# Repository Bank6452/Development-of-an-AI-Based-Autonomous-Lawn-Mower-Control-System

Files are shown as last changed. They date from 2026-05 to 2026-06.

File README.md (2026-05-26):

# 🚜 Autonomous Lawn Mower Robot — ROS2 & STM32

<div align="center">







**โปรเจคจบการศึกษา (Senior Project) ปีการศึกษา 2567**<br>
ระบบรถตัดหญ้าอัตโนมัติควบคุมด้วย ROS 2 — แม่นยำระดับเซนติเมตร ปลอดภัยด้วย AI

<br>

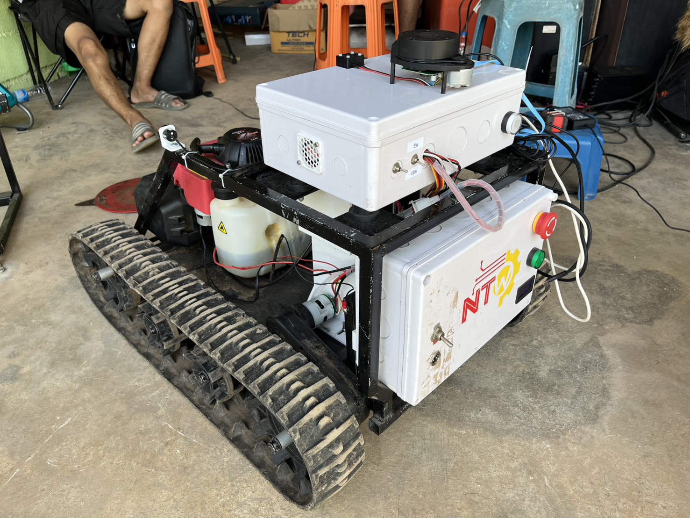
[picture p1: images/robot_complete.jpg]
Robot Complete


</div>

---

## 📖 ภาพรวมโปรเจค

ระบบรถตัดหญ้าอัตโนมัติ (Autonomous Lawn Mower) แบบ **Differential Drive** พัฒนาด้วย **ROS 2 Humble** บน **Raspberry Pi 5** ควบคุมฮาร์ดแวร์ผ่าน **STM32F103C8T6** โดยผสาน Sensor หลายตัว (RTK GPS, LiDAR, IMU, Encoder) ด้วยเทคนิค **Extended Kalman Filter (EKF)** เพื่อการ Localization ที่แม่นยำ พร้อมระบบ **Geofencing**, **YOLO Vision**, และ **Nav2 Navigation Stack**

---

## 🎬 Demo

### 🌿 ตัดหญ้าด้วยระบบอัตโนมัติ (Real Field Test)

<div align="center">

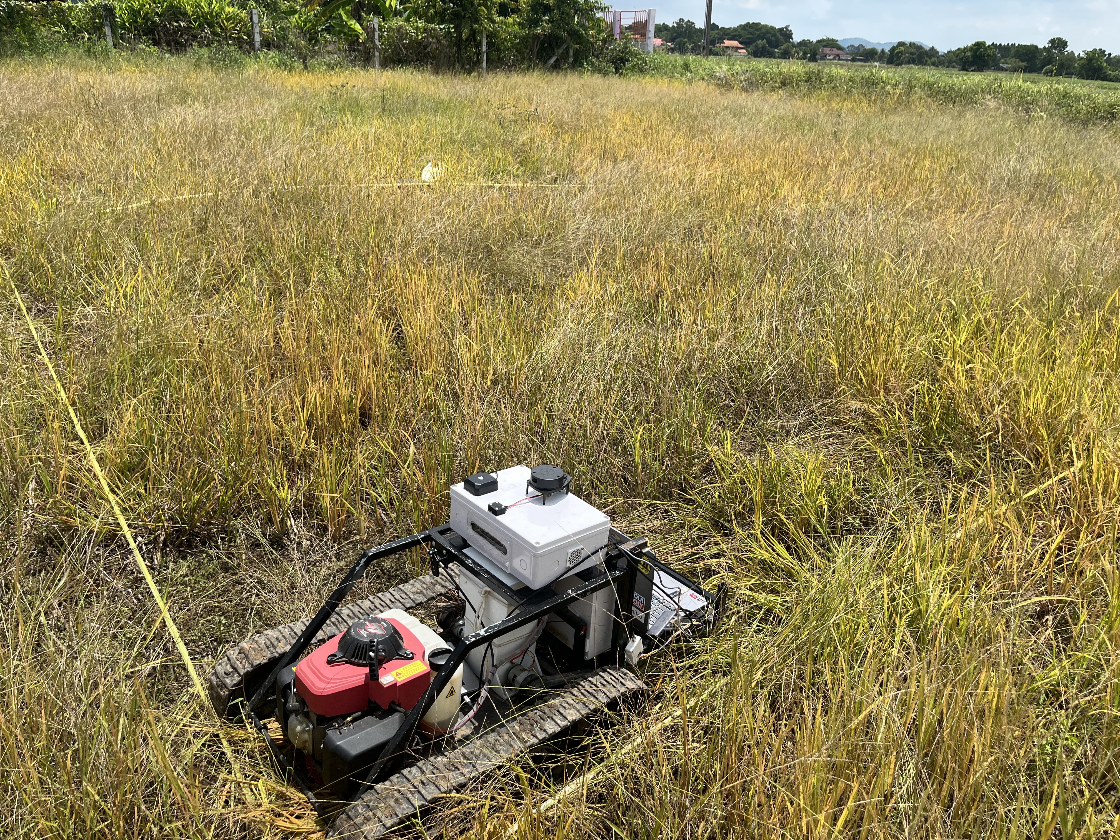
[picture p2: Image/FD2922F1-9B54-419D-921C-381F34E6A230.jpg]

*รถตัดหญ้าอัตโนมัติกำลังปฏิบัติงานในพื้นที่จริง — เห็นแนวการตัดแบบ Zigzag อย่างชัดเจน และเส้นเชือกกำหนดขอบเขต (Geofence) โดยรอบ*

<br>

| รถตัดหญ้าอัตโนมัติขณะทำงานในสนาม | ภาพรวมพื้นที่และแนวการตัด |
|:---:|:---:|
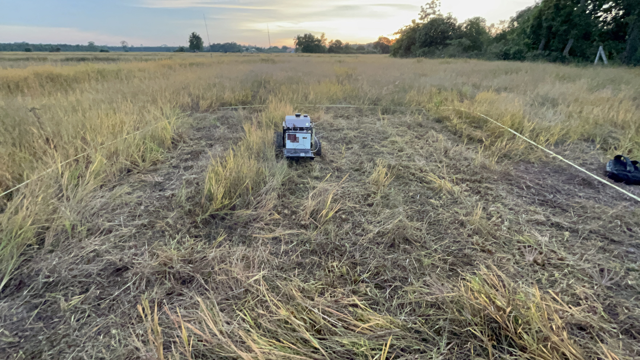
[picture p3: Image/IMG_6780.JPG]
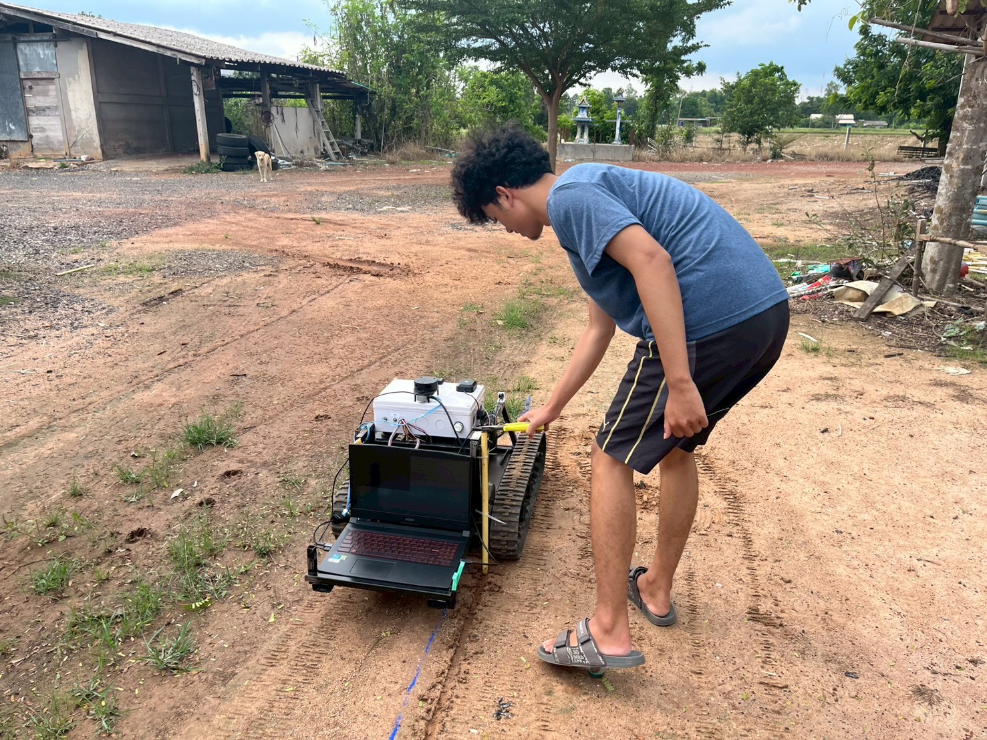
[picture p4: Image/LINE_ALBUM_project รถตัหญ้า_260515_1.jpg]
|  |  |

| | | |
|:---:|:---:|:---:|
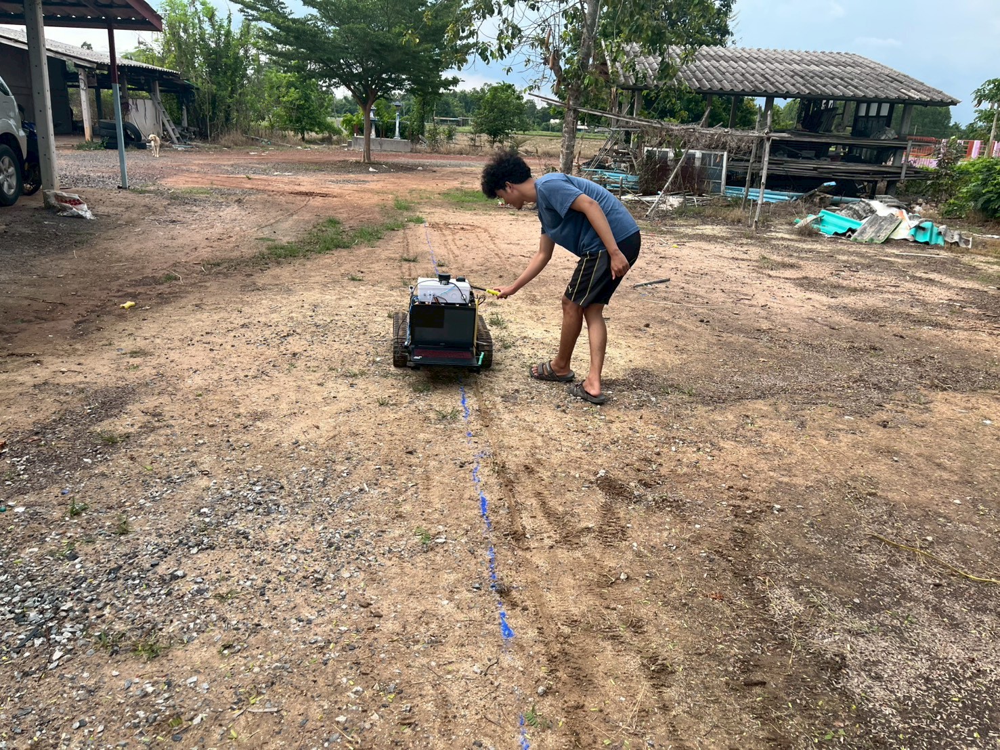
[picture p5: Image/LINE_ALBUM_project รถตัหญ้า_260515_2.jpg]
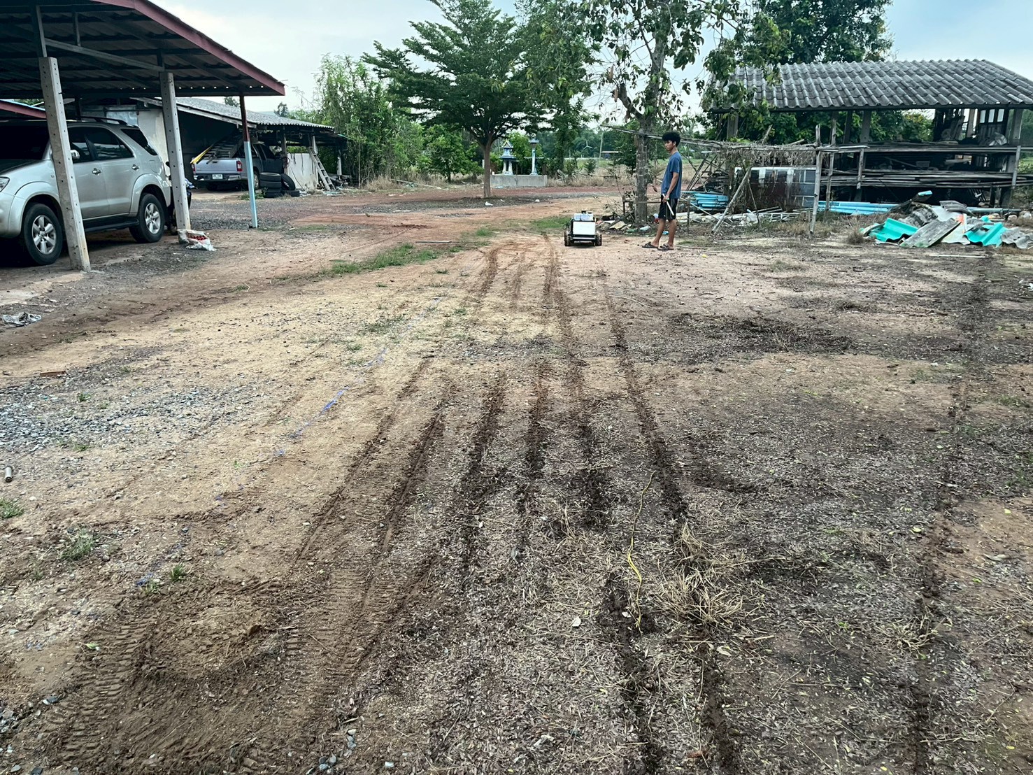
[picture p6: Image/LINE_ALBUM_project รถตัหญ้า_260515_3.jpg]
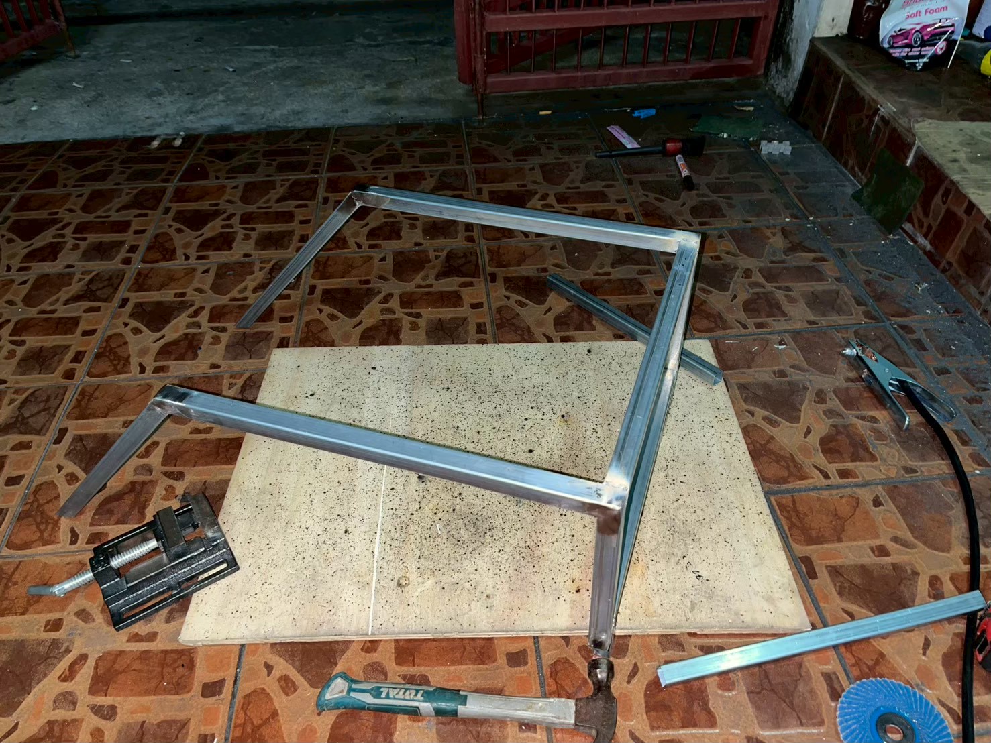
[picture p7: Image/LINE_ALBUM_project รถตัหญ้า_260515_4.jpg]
|  |  |  |
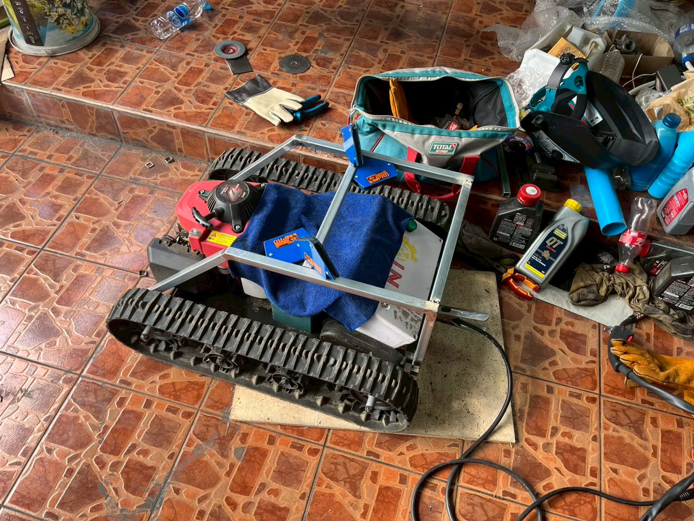
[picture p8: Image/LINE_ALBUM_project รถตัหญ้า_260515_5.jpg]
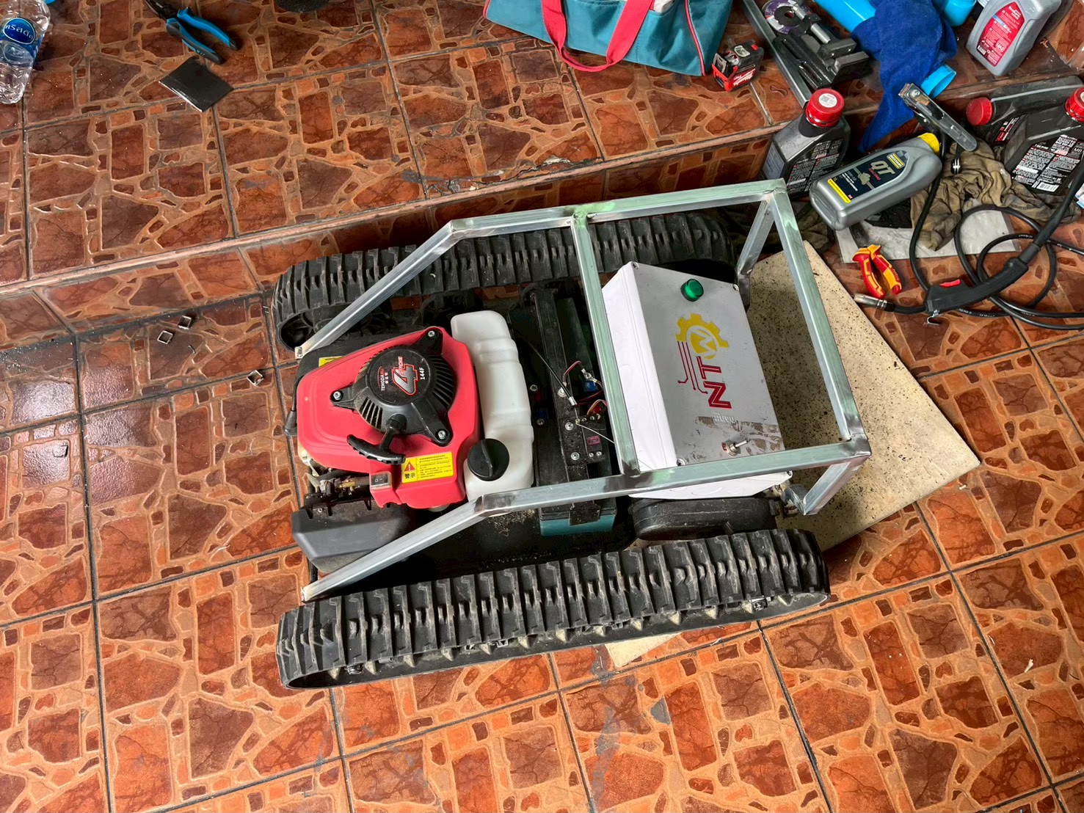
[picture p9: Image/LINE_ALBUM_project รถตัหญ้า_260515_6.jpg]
|  |  |  |

> 📹 **วิดีโอสาธิตการตัดหญ้าจริง:** [`Image/IMG_6782.MOV`](Image/IMG_6782.MOV)

</div>

### ทดสอบในสนามจริง (Setup & Navigation)

<div align="center">

| ตั้งค่าและเตรียมระบบ | วิ่งทดสอบอัตโนมัติ |
|:---:|:---:|
| Setup | Run |

Autonomous Field Test
*รถวิ่งอัตโนมัติครอบคลุมพื้นที่ด้วย Coverage Path Planning*

</div>

### ระบบ AI Vision + LiDAR Mapping (RViz2)

<div align="center">

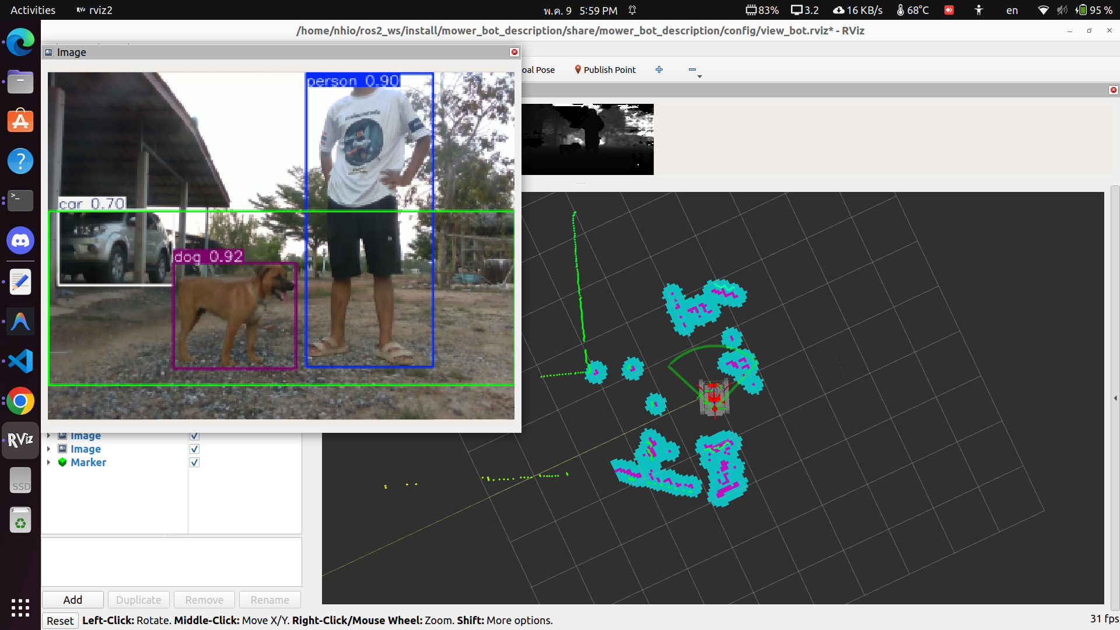
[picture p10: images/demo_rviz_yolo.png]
RViz YOLO Demo

*YOLO ตรวจจับคนและสัตว์ (ซ้าย) + LiDAR Point Cloud Map (ขวา) แบบ Real-time*

</div>

### วิดีโอสาธิต

> 📹 ดูวิดีโอทดสอบในสนามจริงได้ที่: [`Video/demo_field_test.mp4`](Video/demo_field_test.mp4)

---

## ✨ ฟีเจอร์หลัก

| ฟีเจอร์ | รายละเอียด |
|---|---|
| 📡 **RTK GPS + EKF Fusion** | Localization แม่นยำระดับเซนติเมตร โดยรวม GPS และ Wheel Odometry ด้วย Extended Kalman Filter |
| 🗺️ **SLAM & Nav2** | สร้างแผนที่อัตโนมัติ และวางแผนเส้นทางตัดหญ้าแบบ Zig-Zag Coverage Path |
| 🛡️ **Geofencing** | กำหนดขอบเขตการทำงานด้วย GPS Waypoints ป้องกันรถออกนอกพื้นที่ |
| 👁️ **YOLO Vision** | ตรวจจับสิ่งกีดขวางด้วย YOLOv11 + Intel RealSense Depth Camera |
| 💓 **Heartbeat Safety** | ระบบตรวจสอบการเชื่อมต่อ — หยุดรถทันทีเมื่อขาดการเชื่อมต่อ |
| 🔧 **Engine Control** | สตาร์ท/ดับเครื่องยนต์และควบคุม Throttle ผ่าน Software |
| 🎮 **Gazebo Simulation** | จำลองระบบก่อน Deploy จริง รองรับ Nav2 + EKF ใน Simulation |
| 📊 **Real-time Dashboard** | แสดงสถานะระบบแบบ Real-time ผ่าน Terminal |

---

## 🔩 ฮาร์ดแวร์ (Hardware)

<div align="center">

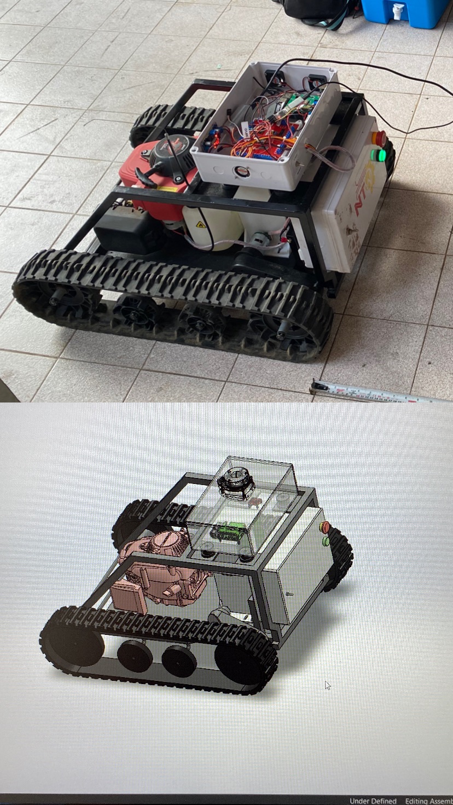
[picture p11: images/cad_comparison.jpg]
CAD vs Real

*CAD Design (ล่าง) เปรียบเทียบกับหุ่นยนต์ที่สร้างจริง (บน)*

</div>

| ชิ้นส่วน | รุ่น/ประเภท | หน้าที่ |
|---|---|---|
| Main Computer | **Raspberry Pi 5** | รัน ROS 2, Navigation, AI |
| Microcontroller | **STM32F103C8T6** (Bluepill) | ควบคุมมอเตอร์, อ่าน Encoder/IMU |
| GPS | **RTK GPS** (NTRIP via KMUTNB65) | Localization แม่นยำ |
| LiDAR | **RPLiDAR** | SLAM และตรวจจับสิ่งกีดขวาง |
| Camera | **Intel RealSense D4xx** | YOLO Object Detection + Depth |
| IMU | **MPU6050 / BNO055** | วัดมุมเอียงและ Angular Velocity |
| Encoder | **Hall Effect Encoder** | วัด Wheel Odometry |
| Drive System | **Rubber Track (สายพาน)** | เคลื่อนที่บนพื้นที่ขรุขระ |
| Engine | **Honda GX Series** | ใบมีดตัดหญ้า |

---

## 🏗️ สถาปัตยกรรมระบบ

```
┌─────────────────────────────────────────────────────────┐
│             Raspberry Pi / Computer 5 (ROS 2)           │
│                                                         │
│  ┌──────────┐  ┌────────────┐  ┌──────────────────────┐ │
│  │  Nav2    │  │   EKF      │  │   Geofence & Planner │ │
│  │ Stack    │──│Localization│  │   (Safety Layer)     │ │
│  └──────────┘  └─────┬──────┘  └──────────────────────┘ │
│       │              │                                  │
│  ┌────▼─────────────▼─────────────────────────────┐     │
│  │              ROS 2 Topic Bus                   │     │
│  └────┬──────────┬─────────┬──────────────────────┘     │
│       │          │         │                            │
│  ┌────▼───┐ ┌────▼───┐ ┌───▼────┐                       │
│  │RPLiDAR │ │RTK GPS │ │ Camera │                       │
│  │ Node   │ │(NTRIP) │ │(YOLO)  │                       │
│  └────────┘ └────────┘ └────────┘                       │
└──────────────────────────┬──────────────────────────────┘
                           │ Serial (UART)
┌──────────────────────────▼──────────────────────────────┐
│                  STM32F103C8T6                          │
│   Motor Driver │ Encoder Reading │ IMU │ Engine Control │
└─────────────────────────────────────────────────────────┘
```

---

## 📂 โครงสร้างโปรเจค

```
ros2_final_project_ws/
├── src/
│   ├── robot_bridge/            # 🧠 ROS2 Package หลัก
│   │   ├── robot_bridge/        # Python nodes
│   │   │   ├── auto_datum_node.py       # ตั้งจุด Datum GPS อัตโนมัติ
│   │   │   ├── geofence_and_planner.py  # Geofence + Coverage Path Planning
│   │   │   ├── geofence_enforcer.py     # Safety: บังคับขอบเขต GPS
│   │   │   ├── lawn_planner.py          # สร้างเส้นทาง Zig-Zag
│   │   │   ├── mow_zigzag.py            # Executor: สั่งวิ่งตามเส้นทาง
│   │   │   ├── ntrip_client.py          # RTK GPS via NTRIP
│   │   │   ├── robot_dashboard.py       # Real-time Status Dashboard
│   │   │   ├── teleop_stm.py            # Teleop → STM32 bridge
│   │   │   └── vision_node.py           # YOLOv11 + RealSense
│   │   ├── launch/
│   │   │   ├── hardware_bringup.launch.py   # เปิดระบบฮาร์ดแวร์ทั้งหมด
│   │   │   ├── localization.launch.py       # EKF Fusion
│   │   │   ├── navigation.launch.py         # Nav2 Stack
│   │   │   └── simulation.launch.py         # Gazebo Simulation
│   │   └── config/
│   │       ├── ekf.yaml             # EKF parameters
│   │       ├── nav2_params.yaml     # Nav2 configuration
│   │       └── twist_mux.yaml       # Velocity command priority
│   │
│   ├── mower_bot_description/   # 🤖 Robot URDF & Simulation
│   └── rplidar_ros/             # 📡 RPLiDAR Driver
│
├── config/                      # ⚙️ Runtime configs
│   ├── lawn_geofence.yaml       # Geofence waypoints (real)
│   ├── lawn_geofence_sim.yaml   # Geofence waypoints (sim)
│   └── udev/                    # USB device rules
│
├── images/                      # 🖼️ Project images (GitHub)
├── Video/                       # 🎬 Demo video
├── scripts/                     # 🔧 Utility & calibration scripts
├── extracted_project/           # 📦 STM32 PlatformIO firmware
├── docs/                        # 📚 Documentation
│
├── start_robot.sh               # 🚀 เปิดระบบหุ่นยนต์จริง (1 คำสั่ง)
├── start_sim.sh                 # 🎮 เปิด Simulation
├── setup_ws.sh                  # ⚡ Source workspace
└── COMMANDS.md                  # 📋 Command cheatsheet
```

---

## 🚀 วิธีติดตั้งและใช้งาน

### ความต้องการของระบบ (Prerequisites)

- **OS:** Ubuntu 22.04 (Jammy)
- **ROS 2:** Humble Hawksbill
- **Python:** 3.10+
- **Hardware:** Raspberry Pi 5 (แนะนำ RAM ≥ 8GB)

### 1. ติดตั้ง ROS 2 Humble

```bash
chmod +x install_ros2_humble.sh install_dependencies.sh
./install_ros2_humble.sh
./install_dependencies.sh
```

### 2. Clone และ Build

```bash
git clone https://github.com/<your-username>/ros2_final_project_ws.git
cd ros2_final_project_ws

pip3 install -r requirements.txt

source /opt/ros/humble/setup.bash
colcon build --symlink-install

source setup_ws.sh
```

### 3. ติดตั้ง udev rules (ทำครั้งเดียว)

```bash
sudo cp config/udev/98-gps.rules   /etc/udev/rules.d/
sudo cp config/udev/99-stm32.rules /etc/udev/rules.d/
sudo udevadm control --reload-rules && sudo udevadm trigger
```

---

## ▶️ การใช้งาน

### 🤖 เปิดระบบหุ่นยนต์จริง

```bash
cd ~/ros2_final_project_ws
./start_robot.sh
```

สคริปต์จะเปิด Terminal tabs อัตโนมัติ:

| แท็บ | ระบบ |
|-----|---|
| 1. HARDWARE | RPLiDAR, STM32, GPS, Camera |
| 2. LOCALIZATION | EKF Sensor Fusion |
| 3. NAVIGATION | Nav2 Path Planning |
| 4. SAFETY & PLANNER | Geofence + Coverage Path |
| 6. MOWING | Mow Executor (พิมพ์ `go` เพื่อเริ่ม) |
| 7. DASHBOARD | Real-time Status |

### 🎮 เปิด Simulation (Gazebo)

```bash
cd ~/ros2_final_project_ws
./start_sim.sh
```

### 🔧 Calibration

```bash
source setup_ws.sh
python3 scripts/calibrate_robot.py linear 1.0    # ระยะทาง
python3 scripts/calibrate_robot.py angular 90    # การหมุน
```

---

## 📡 ROS 2 Topics หลัก

| Topic | Type | รายละเอียด |
|---|---|---|
| `/cmd_vel` | `geometry_msgs/Twist` | คำสั่งความเร็ว (Nav2 → STM32) |
| `/odom_raw` | `nav_msgs/Odometry` | Wheel Odometry จาก STM32 |
| `/odometry/filtered` | `nav_msgs/Odometry` | EKF fused odometry |
| `/fix` | `sensor_msgs/NavSatFix` | RTK GPS position |
| `/scan` | `sensor_msgs/LaserScan` | RPLiDAR data |
| `/camera/yolo/debug_image` | `sensor_msgs/Image` | YOLO detection output |
| `/imu/data` | `sensor_msgs/Imu` | IMU data |

---

## 👥 ทีมผู้จัดทำ

| ชื่อ | รหัสนักศึกษา |
|-----|---|
| **นายพงศธร รอดพิพัฒน์** | 6703016410080 |
| **นายทินภัทร จิตต์บุญ** | 6703016410039 |
| **นายวัชรากร เพกรา** | 6703016410179 |

**อาจารย์ที่ปรึกษา:** ผศ.ดร.สุพจน์ แก้วกรณ์

**สังกัด:** ภาควิชาวิศวกรรมเมคคาทรอนิกส์ — มหาวิทยาลัยเทคโนโลยีพระจอมเกล้าพระนครเหนือ

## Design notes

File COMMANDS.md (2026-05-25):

# 📋 Command Cheatsheet — Mower Bot ROS2 Workspace

> ⚠️ **รันสคริปต์ทุกตัวจาก workspace root เสมอ**
> ```bash
> cd ~/ros2_final_project_ws   # หรือชื่อ folder จริงบนเครื่อง
> ```

---

## 🚀 เริ่มระบบหลัก

```bash
# [หุ่นยนต์จริง] — build + เปิดทุก tab อัตโนมัติ
cd ~/ros2_final_project_ws && colcon build --packages-select robot_bridge --symlink-install && source install/setup.bash
./start_robot.sh

# [Simulation] — build + เปิด Gazebo อัตโนมัติ
cd ~/ros2_final_project_ws
colcon build --packages-select robot_bridge --symlink-install
./start_sim.sh
```

---

## 🔨 Build & Source

```bash
cd ~/ros2_final_project_ws

# Build ทั้งหมด
colcon build --symlink-install

# Build เฉพาะ package
colcon build --packages-select robot_bridge --symlink-install
colcon build --packages-select mower_bot_description --symlink-install

# Source workspace (ทำทุกครั้งหลัง build)
source /opt/ros/humble/setup.bash
source install/setup.bash
```

---

## 🤖 Launch Files

```bash
cd ~/ros2_final_project_ws && source install/setup.bash

# Terminal 1 — Hardware
ros2 launch robot_bridge hardware_bringup.launch.py

# Terminal 2 — Localization (EKF)
ros2 launch robot_bridge localization.launch.py

# Terminal 3 — Navigation (Nav2)
ros2 launch robot_bridge navigation.launch.py

# Simulation (Gazebo)
ros2 launch robot_bridge simulation.launch.py
ros2 launch mower_bot_description launch_sim.launch.py

# Test IMU
ros2 launch robot_bridge imu_test.launch.py
```

---

## 🗺️ Nav2 + SLAM + Map

```bash
# SLAM
ros2 launch slam_toolbox online_async_launch.py use_sim_time:=True

# Nav2 bringup (Simulation)
ros2 launch nav2_bringup bringup_launch.py \
  use_sim_time:=True \
  map:=~/ros2_final_project_ws/src/mower_bot_description/maps/my_map.yaml \
  params_file:=~/ros2_final_project_ws/src/mower_bot_description/config/my_nav2_params.yaml

# RViz2
rviz2 -d ~/ros2_final_project_ws/src/mower_bot_description/config/view_bot.rviz
ros2 launch nav2_bringup bringup_launch.py use_sim_time:=True \
  map:=~/ros2_final_project_ws/src/mower_bot_description/maps/my_map.yaml

# ดู TF frames
ros2 run tf2_tools view_frames
```

---

## 🌿 Geofence & Planner

```bash
cd ~/ros2_final_project_ws && source install/setup.bash

# Geofence Enforcer (หุ่นยนต์จริง)
ros2 run robot_bridge geofence_enforcer \
  --ros-args -p geofence_file:=$(pwd)/config/lawn_geofence.yaml

# Geofence Enforcer (Simulation)
ros2 run robot_bridge geofence_enforcer \
  --ros-args -p geofence_file:=$(pwd)/config/lawn_geofence_sim.yaml

# Lawn Planner
ros2 run robot_bridge lawn_planner \
  --ros-args -p geofence_file:=$(pwd)/config/lawn_geofence.yaml

# Geofence + Planner รวม
ros2 run robot_bridge geofence_and_planner \
  --ros-args -p geofence_file:=$(pwd)/config/lawn_geofence.yaml

# Mowing Executor
ros2 run robot_bridge mow_zigzag
```

---

## 📡 GPS / NTRIP

```bash
./start_ntrip.sh

# หรือรันตรง
cd ~/ros2_final_project_ws && source install/setup.bash
ros2 run robot_bridge ntrip_client --ros-args \
  -p ip:="192.168.1.108" \
  -p port:=2116 \
  -p mountpoint:="KMUTNB65"
```

---

## 📷 Camera & Vision

```bash
cd ~/ros2_final_project_ws && source install/setup.bash

# เปิดกล้อง RealSense
ros2 launch realsense2_camera rs_launch.py \
  enable_color:=true enable_depth:=true \
  rgb_camera.color_profile:=640x480x15 \
  depth_module.profile:=640x480x15 \
  initial_reset:=true

# Vision Node (YOLO)
ros2 run robot_bridge vision_node

# ตรวจสอบ FPS กล้อง
ros2 topic hz /camera/yolo/debug_image
ros2 topic hz /camera/camera/color/image_raw

# GPU
nvidia-smi
```

---

## 🕹️ Teleop & Dashboard

```bash
cd ~/ros2_final_project_ws && source install/setup.bash

ros2 run teleop_twist_keyboard teleop_twist_keyboard
ros2 run robot_bridge robot_dashboard
ros2 run robot_bridge straight_line_test

# ส่ง cmd_vel โดยตรง
ros2 topic pub --once /cmd_vel_teleop geometry_msgs/msg/Twist \
  "{linear: {x: 0.2, y: 0.0, z: 0.0}, angular: {x: 0.0, y: 0.0, z: 0.0}}"
```

---

## 🧭 IMU / Compass

```bash
# Set zero compass (หันไปทางเหนือก่อน)
ros2 topic pub --once /imu/set_north std_msgs/msg/Empty {}

# Monitor IMU
ros2 topic echo /camera/camera/imu --field angular_velocity
ros2 topic echo /odometry/filtered --field pose.pose.orientation
```

---

## 🔧 Calibration

```bash
cd ~/ros2_final_project_ws && source install/setup.bash

# Calibrate (linear/angular) — ต้องรัน hardware_bringup ก่อน
python3 scripts/calibrate_robot.py linear 1.0
python3 scripts/calibrate_robot.py angular 90

python3 scripts/calibrate_linear.py

# Monitor topics
python3 scripts/topic_monitor.py
python3 scripts/monitor_imu_robot.py
```

---

## 🔌 USB / Serial Ports

```bash
ls /dev/tty{ACM,USB}*
ls /dev/serial/by-id/

# ติดตั้ง udev rules (ทำครั้งเดียว)
sudo cp config/udev/98-gps.rules   /etc/udev/rules.d/
sudo cp config/udev/99-stm32.rules /etc/udev/rules.d/
sudo udevadm control --reload-rules && sudo udevadm trigger
```

---

## 📊 Topics & Diagnostics

```bash
ros2 topic list
ros2 topic echo /ultrasonic/center
ros2 run rqt_graph rqt_graph

# Diagnostic check (บันทึก log 20 วิ)
./diagnostic_check.sh
```

---

## ⚙️ Misc

```bash
# Stop ทุก node + daemon
killall -9 gzserver gzclient 2>/dev/null
ros2 daemon stop && ros2 daemon start

# Snapshot environment
./snapshot_env.sh
```

---

## 🗺️ Map Tile URL (Google Satellite)
```
https://mt1.google.com/vt/lyrs=s&x={x}&y={y}&z={z}
```

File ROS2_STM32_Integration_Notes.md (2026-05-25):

## ข้อสรุปการเชื่อมต่อและ Protocol ระหว่าง ROS2 กับ STM32 / Arduino

### 1. โครงสร้างปัจจุบันของฝั่ง STM32 (อ้างอิงจากโค้ดที่มีอยู่)
จากการตรวจสอบไฟล์ทั้งหมดในโปรเจกต์ (รวมถึง `main.cpp`, `main.txt`, `motor_control.cpp`, `engine_control.cpp` และไฟล์อื่นๆ ในโฟลเดอร์ `src/` และ `include/`) **ยังไม่มีการเขียนโค้ดสำหรับ "รับคำสั่ง" (รับข้อมูลเข้าผ่าน Serial) ไว้อยู่ใน STM32 เลยครับ** มีเพียงแค่การส่งข้อมูลออก (Transmit ข้อมูลจำพวก IMU, Encoder, Ultrasonic) เท่านั้น ดังนั้นเราจำเป็นต้องเขียนส่วนการรอรับข้อมูลผ่าน `Serial1.available()` และแยกแยะข้อความเพิ่มเข้าไปใน STM32 ครับ

ฟังก์ชันที่มีอยู่แล้วในฝั่ง STM32 พร้อมถูกเรียกใช้งานเมื่อได้รับคำสั่ง มีดังนี้:
- `driveMotors(int speedL, int speedR)`: ควบคุมสายพานซ้ายและขวา รับค่าช่วง `-100` ถึง `100`
- `setThrottle(int percent)`: ควบคุมคันเร่ง (Servo) รับค่าช่วง `0` ถึง `100`
- `startEngine()`, `powerOn()`, `powerOff()`: สั่งงานเครื่องยนต์/รีเลย์

---

### 2. ทางแก้และรูปแบบ Protocol ที่นำเสนอ (สำหรับเขียนเพิ่มใน STM32 และ ROS2)
เนื่องจากเราต้องเพิ่มการรับข้อมูลผ่าน `Serial1` บน STM32 เสนอให้ใช้ Protocol เป็น String ที่ง่ายต่อการแยกแยะ (เหมือนกับสิ่งที่ STM ส่งหา ROS) ดังนี้ครับ:

**รูปแบบคำสั่งส่งจาก ROS2 -> STM32:**
1. **การขับเคลื่อน (Motor Control):** 
   - รูปแบบ: `M,<speedL>,<speedR>\n` (ต้องลงท้ายด้วยการขึ้นบรรทัดใหม่ `\n` เพื่อให้รู้จุดจบคำสั่ง)
   - ตัวอย่าง: `M,50,-50\n` (ล้อซ้ายหมุนไปหน้า 50, ล้อขวาหมุนกลับหลัง -50 ใช้สำหรับการหมุนตัวหรือเลี้ยวแบบรถถัง)
2. **การควบคุมคันเร่ง (Engine Throttle):**
   - รูปแบบ: `T,<percent>\n`
   - ตัวอย่าง: `T,80\n` (กดคันเร่งไปที่ 80%)
3. **การสั่งการเครื่องยนต์ (Engine Status):**
   - รูปแบบ: `E,<status>\n`
   - ตัวอย่าง: `E,1\n` (สั่งเรียกใชังานฟังก์ชัน `startEngine()`), `E,2\n` (เรียกใช้ `powerOn()`), `E,0\n` (เรียกใช้ `powerOff()`)

---

### 3. แนวทางการแยก Ultrasonic ไปใช้ Arduino
ตามไอเดียที่จะใช้ Arduino ตัวเล็กๆ รับภาระไว้อ่านค่าเซ็นเซอร์ Ultrasonic 3 ตัว และส่งค่าให้ ROS2 ตรงๆ เพื่อลดภาระการหน่วงเวลา (Block) ของจังหวะสัญญาณเสียงในบอร์ดหลัก STM32 

**รูปแบบ Protocol จาก Arduino -> ROS2 (คงรูปแบบเดิมจาก STM32 ไว้ จะได้ไม่ต้องแก้โค้ดฝั่งรับของ ROS มาก):**
- รูปแบบ: `U,<dL>,<dC>,<dR>\n`
- ตัวอย่าง: `U,20.5,150.2,40.0\n` (ระยะที่สะท้อนกลับมาหน่วยเป็นเซนติเมตร)

**แนวทางการเขียนโค้ด Arduino:**
- ให้ใช้วิธี **Non-blocking (ไม่ใช้ `delay()` ปกติ ยกเว้นตอน Trigger สั้นๆ ระดับ Microseconds)** ในการอ่านค่าเซ็นเซอร์
- เว้นระยะเวลาพักให้เสียงสะท้อน (Echo ชุดเดิม) หายไปก่อนที่จะสั่งอ่านเซ็นเซอร์ตัวถัดไปประมาณ **35ms** ป้องกัน Crosstalk (เสียงของตัวซ้ายไปเข้าตัวกลาง/ตัวขวา)
- แล้วก็ส่งค่าเซ็นเซอร์ล่าสุด (หรือใส่ค่า -2.0 ไว้ป้องกันกรณีเกินระยะวัด/timeout) ทุกๆ 100ms ออกมาทาง Serial 

---

### 4. แนวทางการใช้งานร่วมกับ ROS2 (Teleop & Serial Node)
ในฝั่งของ ROS2 เพื่อให้ทำงานร่วมกับระบบดังกล่าว เราต้องแบ่งการจัดการออกเป็นฝั่งรับ/ส่ง:

1. **ส่งคำสั่งเข้า STM32 (Teleop Converter Node):**
   - โหนดนี้จะทำหน้าที่ `Subscribe` Topic ที่ชื่อว่า `/cmd_vel` (ใช้ Message แบบ `geometry_msgs/msg/Twist`)
   - นำค่า `linear.x` (ความเร็วเดินหน้า/ถอยหลัง) และ `angular.z` (ความเร็วหมุนซ้าย/ขวา) มาคำนวณผ่านสมการ Kinematics สำหรับหุ่นยนต์ล้อสายพาน (Differential Drive)
   - พอคำนวณได้ความเร็วของล้อซ้ายและล้อขวาแล้ว ให้จับแปลงหรือ Map ค่านั้นให้อยู่ในช่วง `-100` ถึง `100` ตามที่มอเตอร์ของท่านร้องขอ
   - จากนั้นประกอบสตริงรูปแบบ `M,<ค่าล้อซ้าย>,<ค่าล้อขวา>\n` แล้วส่งผ่าน Serial (ไปยังพอร์ตของ STM32) เข้าไป

2. **รับข้อมูลกลับจาก Arduino / STM32 (Serial Reader Node):**
   - ฝั่ง Arduino: โหนดจะคอยอ่านบรรทัด `Serial.readline( )` จากพอร์ต `/dev/ttyUSB` (พอร์ตของ Arduino) 
   - เมื่อเจอบรรทัดที่ขึ้นต้นด้วยตัวอักษร `U,` จะทำการตัดคำ (Split string) เพื่อแยกระยะกะจัดทั้ง 3 ตัวออกมา ส่งเข้าไปในหัวข้อ Topic (เช่น Publish ให้ประเภทข้อมูล `sensor_msgs/msg/Range`) เพี่อส่งให้ส่วนประมวลผล Navigation เอาไปคำนวณการเลี่ยงชน (Obstacle avoidance)
   - สำหรับฝั่ง STM32 (ข้อมูล IMU หรือ Encoder) ก็สามารถทำวิธีเดียวกันแยกตามตัวอักษร `I,` หรือ `D,` แล้วใส่ ROS2 Topics ได้เลย

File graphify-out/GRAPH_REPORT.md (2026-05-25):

# Graph Report - ros2_ws  (2026-05-08)

## Corpus Check
- 220 files · ~10,642,703 words
- Verdict: corpus is large enough that graph structure adds value.

## Summary
- 831 nodes · 990 edges · 47 communities detected
- Extraction: 97% EXTRACTED · 3% INFERRED · 0% AMBIGUOUS · INFERRED: 27 edges (avg confidence: 0.8)
- Token cost: 0 input · 0 output

## Community Hubs (Navigation)
- [[_COMMUNITY_Community 0|Community 0]]
- [[_COMMUNITY_Community 1|Community 1]]
- [[_COMMUNITY_Community 2|Community 2]]
- [[_COMMUNITY_Community 3|Community 3]]
- [[_COMMUNITY_Community 4|Community 4]]
- [[_COMMUNITY_Community 5|Community 5]]
- [[_COMMUNITY_Community 6|Community 6]]
- [[_COMMUNITY_Community 7|Community 7]]
- [[_COMMUNITY_Community 8|Community 8]]
- [[_COMMUNITY_Community 9|Community 9]]
- [[_COMMUNITY_Community 10|Community 10]]
- [[_COMMUNITY_Community 11|Community 11]]
- [[_COMMUNITY_Community 12|Community 12]]
- [[_COMMUNITY_Community 13|Community 13]]
- [[_COMMUNITY_Community 15|Community 15]]
- [[_COMMUNITY_Community 16|Community 16]]
- [[_COMMUNITY_Community 17|Community 17]]
- [[_COMMUNITY_Community 18|Community 18]]
- [[_COMMUNITY_Community 19|Community 19]]
- [[_COMMUNITY_Community 20|Community 20]]
- [[_COMMUNITY_Community 21|Community 21]]
- [[_COMMUNITY_Community 22|Community 22]]
- [[_COMMUNITY_Community 23|Community 23]]
- [[_COMMUNITY_Community 24|Community 24]]
- [[_COMMUNITY_Community 25|Community 25]]
- [[_COMMUNITY_Community 26|Community 26]]
- [[_COMMUNITY_Community 27|Community 27]]
- [[_COMMUNITY_Community 28|Community 28]]
- [[_COMMUNITY_Community 29|Community 29]]
- [[_COMMUNITY_Community 30|Community 30]]
- [[_COMMUNITY_Community 31|Community 31]]
- [[_COMMUNITY_Community 32|Community 32]]
- [[_COMMUNITY_Community 38|Community 38]]
- [[_COMMUNITY_Community 39|Community 39]]
- [[_COMMUNITY_Community 40|Community 40]]
- [[_COMMUNITY_Community 41|Community 41]]
- [[_COMMUNITY_Community 42|Community 42]]
- [[_COMMUNITY_Community 43|Community 43]]
- [[_COMMUNITY_Community 44|Community 44]]
- [[_COMMUNITY_Community 45|Community 45]]
- [[_COMMUNITY_Community 46|Community 46]]
- [[_COMMUNITY_Community 47|Community 47]]
- [[_COMMUNITY_Community 48|Community 48]]
- [[_COMMUNITY_Community 51|Community 51]]
- [[_COMMUNITY_Community 52|Community 52]]
- [[_COMMUNITY_Community 54|Community 54]]
- [[_COMMUNITY_Community 68|Community 68]]

## God Nodes (most connected - your core abstractions)
1. `TopicMonitor` - 27 edges
2. `TeleopSTMNode` - 23 edges
3. `RobotDashboard` - 18 edges
4. `Node` - 17 edges
5. `GeofenceSystem` - 16 edges
6. `GeofenceSystem` - 12 edges
7. `NtripClient` - 11 edges
8. `MowZigzag` - 10 edges
9. `UltrasonicToPointCloud` - 10 edges
10. `setup()` - 9 edges

## Surprising Connections (you probably didn't know these)
- `setup()` --calls--> `initUltrasonic()`  [INFERRED]
  Final_project/Final_Project_Main/src/main.cpp → esp32_bno055_pio/src/ultrasonic.cpp
- `GeofenceSystem` --inherits--> `Node`  [EXTRACTED]
  geofence_enforcer.py → Final_project/ai/yolo_depth_node.py
- `TopicMonitor` --inherits--> `Node`  [EXTRACTED]
  topic_monitor.py → Final_project/ai/yolo_depth_node.py
- `AutoDatumNode` --inherits--> `Node`  [EXTRACTED]
  src/robot_bridge/robot_bridge/auto_datum_node.py → Final_project/ai/yolo_depth_node.py
- `MowZigzag` --inherits--> `Node`  [EXTRACTED]
  src/robot_bridge/robot_bridge/mow_zigzag.py → Final_project/ai/yolo_depth_node.py

## Communities (147 total, 14 thin omitted)

### Community 0 - "Community 0"
Cohesion: 0.06
Nodes (16): main(), YoloDepthNode, Node, LawnPlanner, main(), main(), VisionNode, LinearCalibrator (+8 more)

### Community 1 - "Community 1"
Cohesion: 0.08
Nodes (27): _checkWSAStartup(), clearRxCache(), connect(), CreateSocket(), DGramSocketImpl(), enableNoDelay(), getAddressAsString(), getAddressType() (+19 more)

### Community 2 - "Community 2"
Cohesion: 0.08
Nodes (26): clearRxCache(), connect(), CreateSocket(), DGramSocketImpl(), enableNoDelay(), getAddressType(), getPort(), getRawAddress() (+18 more)

### Community 3 - "Community 3"
Cohesion: 0.09
Nodes (26): clearRxCache(), connect(), CreateSocket(), DGramSocketImpl(), enableNoDelay(), getAddressType(), getPort(), getRawAddress() (+18 more)

### Community 4 - "Community 4"
Cohesion: 0.09
Nodes (24): initBattery(), updateBattery(), getEncoderData(), handleEncoderL(), handleEncoderR(), setupEncoders(), initEngineSystem(), powerOff() (+16 more)

### Community 6 - "Community 6"
Cohesion: 0.12
Nodes (12): main(), NtripClient, อ่านข้อมูล NMEA ดิบทจากบอร์ด GPS แล้ว Publish ลง Topic, อ่านข้อมูล NMEA ดิบทจากบอร์ด GPS แล้ว Publish ลง Topic, รับ NMEA (GGA) เพื่อส่งกลับไปให้เซิร์ฟเวอร์ VRS, รับ NMEA (GGA) เพื่อส่งกลับไปให้เซิร์ฟเวอร์ VRS, อ่านข้อมูล RTCM จากเซิร์ฟเวอร์และเขียนลงบอร์ด GPS, อ่านข้อมูล RTCM จากเซิร์ฟเวอร์และเขียนลงบอร์ด GPS (+4 more)

### Community 7 - "Community 7"
Cohesion: 0.11
Nodes (4): main(), รับสถานะความปลอดภัยที่ผ่านการตัดสินใจมาแล้วจาก teleop_stm, ใช้สำหรับแสดงระยะวัตถุที่ใกล้ที่สุดเท่านั้น (ไม่ต้องคำนวณ Safety เอง), RobotDashboard

### Community 8 - "Community 8"
Cohesion: 0.2
Nodes (18): add_package_runtime_dependencies(), _append_unique_value(), get_commands(), get_packages(), handle_dsv_types_except_source(), _include_comments(), main(), order_packages() (+10 more)

### Community 9 - "Community 9"
Cohesion: 0.2
Nodes (18): add_package_runtime_dependencies(), _append_unique_value(), get_commands(), get_packages(), handle_dsv_types_except_source(), _include_comments(), main(), order_packages() (+10 more)

### Community 10 - "Community 10"
Cohesion: 0.13
Nodes (6): clearDTR(), close(), getTermBaudBitmap(), _init(), open(), raw_serial()

### Community 11 - "Community 11"
Cohesion: 0.14
Nodes (5): clearDTR(), close(), _init(), open(), raw_serial()

### Community 12 - "Community 12"
Cohesion: 0.17
Nodes (10): _getSampleDelayOffsetInDenseMode(), _getSampleDelayOffsetInExpressMode(), _getSampleDelayOffsetInUltraBoostMode(), _getSampleDelayOffsetInUltraDenseMode(), onData(), _onScanNodeCapsuleData(), _onScanNodeDenseCapsuleData(), _onScanNodeUltraCapsuleData() (+2 more)

### Community 13 - "Community 13"
Cohesion: 0.2
Nodes (4): GeofenceSystem, main(), เก็บค่า GPS ล่าสุดไว้สำหรับ Record Mode เท่านั้น, ตรวจสอบตำแหน่งหุ่นยนต์จาก TF map->base_link ที่ 10Hz

### Community 15 - "Community 15"
Cohesion: 0.22
Nodes (5): main(), MowZigzag, สร้าง Path จาก from_pose (ตำแหน่งหุ่นปัจจุบัน) ไปยัง chunk         เหมือนกับที่, ส่ง Path ก้อนเดียวให้ Nav2 และรอให้เสร็จ, แบ่ง poses ออกเป็นก้อนๆ โดยหั่น "ก่อน" จุดเลี้ยว         เพื่อให้:         - แต่

### Community 17 - "Community 17"
Cohesion: 0.23
Nodes (7): angleLessThan(), ascendScanData_(), getAngle(), getDistanceQ2(), RawSampleNodeHolder, ScanDataHolder, setAngle()

### Community 18 - "Community 18"
Cohesion: 0.27
Nodes (8): AsyncTransceiver(), _changeBufSize(), cleanData(), fillData(), openChannelAndBind(), ProtocolMessage(), setDataBuf(), unbindAndClose()

### Community 20 - "Community 20"
Cohesion: 0.27
Nodes (3): main(), Temporal Hold Filter (Tuned for JSN-SR04T)         If the sensor goes blind (-1, UltrasonicToPointCloud

### Community 21 - "Community 21"
Cohesion: 0.2
Nodes (6): connect(), createLidarDriver(), createSerialPortChannel(), SerialPortChannel, createTcpChannel(), TcpChannel

### Community 22 - "Community 22"
Cohesion: 0.2
Nodes (8): ILidarDriver(), checkMotorCtrlSupport(), getDeviceInfo(), getHealth(), getLidarIpConf(), getScanDataWithIntervalHq(), getTypicalScanMode(), grabScanDataHq()

### Community 23 - "Community 23"
Cohesion: 0.24
Nodes (5): AutoDatumNode, main(), อ่าน datum จากไฟล์ geofence, เรียกครั้งเดียว (One-shot) หลังจาก 3 วินาที, เช็คผลลัพธ์จาก Service Call

### Community 24 - "Community 24"
Cohesion: 0.2
Nodes (8): บันทึกค่า Offset ลงไฟล์, บันทึกค่า Offset ลงไฟล์, บันทึกค่า Offset ลงไฟล์, บันทึกค่า Offset ลงไฟล์, คำสั่งตั้งค่าหน้าหุ่นให้เป็นทิศเหนือ (0 องศา), คำสั่งตั้งค่าหน้าหุ่นให้เป็นทิศเหนือ (0 องศา), คำสั่งตั้งค่าหน้าหุ่นให้เป็นทิศเหนือ (0 องศา), คำสั่งตั้งค่าหน้าหุ่นให้เป็นทิศเหนือ (0 องศา)

### Community 25 - "Community 25"
Cohesion: 0.2
Nodes (8): ค้นหาพอร์ตอัตโนมัติ (ลองหา CH340 ก่อน ถ้าไม่เจอเอาพอร์ตที่ว่างอยู่), ค้นหาพอร์ตอัตโนมัติ (ลองหา CH340 ก่อน ถ้าไม่เจอเอาพอร์ตที่ว่างอยู่), ค้นหาพอร์ตอัตโนมัติ (ลองหา CH340 ก่อน ถ้าไม่เจอเอาพอร์ตที่ว่างอยู่), ค้นหาพอร์ตอัตโนมัติ (หาเฉพาะ CH340 เท่านั้น), วนลูปตรวจสอบและพยายามเชื่อมต่อพอร์ต USB อัตโนมัติ, วนลูปตรวจสอบและพยายามเชื่อมต่อพอร์ต USB อัตโนมัติ, วนลูปตรวจสอบและพยายามเชื่อมต่อพอร์ต USB อัตโนมัติ, วนลูปตรวจสอบและพยายามเชื่อมต่อพอร์ต USB อัตโนมัติ

### Community 26 - "Community 26"
Cohesion: 0.22
Nodes (8): parse_incoming_data(), ตรวจสอบ Checksum ข้อมูล IMU ที่ส่งมาจาก STM32, ส่งคำสั่งคุมทิศทาง (C) ตามโปรโตคอลใหม่: C,Dir,Speed,Chk     direction: 'F', 'B', ส่งคำสั่งหยุดฉุกเฉิน (E): E,state,chk, แยกแยะข้อมูล I (IMU) และ D (Encoder), send_control_command(), send_emergency(), verify_imu_checksum()

### Community 27 - "Community 27"
Cohesion: 0.25
Nodes (4): CreateInstance(), LIDARSampleDataUnpacker(), LIDARSampleDataUnpackerImpl, _registerDataUnpackerHandlers()

### Community 28 - "Community 28"
Cohesion: 0.36
Nodes (5): estimateLength(), exitLoopMode(), onDecodeReset(), onEncodeData(), RPLidarProtocolCodec()

### Community 32 - "Community 32"
Cohesion: 0.29
Nodes (6): วิเคราะห์ข้อมูลจาก LiDAR เพื่อตรวจจับสิ่งกีดขวางด้านหน้า, วิเคราะห์ข้อมูลจาก LiDAR เพื่อตรวจจับสิ่งกีดขวางด้านหน้า, วิเคราะห์ข้อมูลจาก LiDAR เพื่อตรวจจับสิ่งกีดขวางด้านหน้า, วิเคราะห์ข้อมูลจาก LiDAR เพื่อตรวจจับสิ่งกีดขวางด้านหน้า, วิเคราะห์ข้อมูลจาก LiDAR เพื่อตรวจจับสิ่งกีดขวางด้านหน้า, วิเคราะห์ข้อมูลจาก LiDAR เพื่อตรวจจับสิ่งกีดขวางด้านหน้า

### Community 38 - "Community 38"
Cohesion: 0.33
Nodes (4): โหลดค่า Offset จากไฟล์ ถ้าไม่มีให้ใช้ค่า Default (160.0), โหลดค่า Offset จากไฟล์ ถ้าไม่มีให้ใช้ค่า Default (160.0), โหลดค่า Offset จากไฟล์ ถ้าไม่มีให้ใช้ค่า Default (160.0), โหลดค่า Offset จากไฟล์ ถ้าไม่มีให้ใช้ค่า Default (160.0)

### Community 39 - "Community 39"
Cohesion: 0.33
Nodes (5): วาดพัดสีแดง/เขียว ใน RViz เพื่อโชว์ระยะปลอดภัยของ LiDAR, วาดพัดสีแดง/เขียว ใน RViz โดยหันไปทางด้านหน้าหุ่นยนต์ (มุม 180 ของ LiDAR), วาดพัดสีแดง/เขียว ใน RViz โดยหันไปทางด้านหน้าหุ่นยนต์ (มุม 180 ของ LiDAR), วาดพัดสีแดง/เขียว ใน RViz โดยหันไปทางด้านหน้าหุ่นยนต์ (มุม 180 ของ LiDAR), วาดพัดสีแดง/เขียว ใน RViz โดยหันไปทางด้านหน้าหุ่นยนต์ (มุม 180 ของ LiDAR)

### Community 40 - "Community 40"
Cohesion: 0.33
Nodes (5): เก็บค่าพิกัดล่าสุดที่ EKF คำนวณเสร็จแล้ว, เก็บค่าพิกัดล่าสุดที่ EKF คำนวณเสร็จแล้ว, เก็บค่าพิกัดล่าสุดที่ EKF คำนวณเสร็จแล้ว, เก็บค่าพิกัดล่าสุดที่ EKF คำนวณเสร็จแล้ว, เก็บค่าพิกัดล่าสุดที่ EKF คำนวณเสร็จแล้ว

### Community 41 - "Community 41"
Cohesion: 0.33
Nodes (5): ยกเลิกงาน Nav2 เมื่อหยุดรอนานเกินไป, ยกเลิกงาน Nav2 เมื่อหยุดรอนานเกินไป, ยกเลิกงาน Nav2 เมื่อหยุดรอนานเกินไป, ยกเลิกงาน Nav2 เมื่อหยุดรอนานเกินไป, ยกเลิกงาน Nav2 เมื่อหยุดรอนานเกินไป

### Community 42 - "Community 42"
Cohesion: 0.6
Nodes (3): colcon_append_unique_value(), colcon_package_source_powershell_script(), colcon_prepend_unique_value()

### Community 44 - "Community 44"
Cohesion: 0.7
Nodes (4): bitrev(), cal(), getResult(), init()

### Community 46 - "Community 46"
Cohesion: 0.4
Nodes (4): รับสัญญาณหยุดฉุกเฉินจาก AI Vision, รับสัญญาณหยุดฉุกเฉินจาก AI Vision, รับสัญญาณหยุดฉุกเฉินจาก AI Vision, รับสัญญาณหยุดฉุกเฉินจาก AI Vision

## Knowledge Gaps
- **78 isolated node(s):** `# NOTE: Using a slightly different mapping to match user's "Pitch is Yaw" observ`, `Find packages based on colcon-specific files created during installation.      :`, `Check the path and if it exists extract the packages runtime dependencies.`, `Order packages topologically.      :param dict packages: A mapping from package`, `Reduce the set of packages to the ones part of the circular dependency.      :pa` (+73 more)
  These have ≤1 connection - possible missing edges or undocumented components.
- **14 thin communities (<3 nodes) omitted from report** — run `graphify query` to explore isolated nodes.

## Suggested Questions
_Questions this graph is uniquely positioned to answer:_

- **Why does `Node` connect `Community 0` to `Community 5`, `Community 6`, `Community 7`, `Community 13`, `Community 15`, `Community 16`, `Community 19`, `Community 20`, `Community 23`, `Community 29`?**
  _High betweenness centrality (0.081) - this node is a cross-community bridge._
- **Why does `TeleopSTMNode` connect `Community 19` to `Community 0`, `Community 32`, `Community 38`, `Community 39`, `Community 40`, `Community 41`, `Community 46`, `Community 24`, `Community 25`?**
  _High betweenness centrality (0.041) - this node is a cross-community bridge._
- **Why does `TopicMonitor` connect `Community 5` to `Community 0`?**
  _High betweenness centrality (0.018) - this node is a cross-community bridge._
- **What connects `# NOTE: Using a slightly different mapping to match user's "Pitch is Yaw" observ`, `Find packages based on colcon-specific files created during installation.      :`, `Check the path and if it exists extract the packages runtime dependencies.` to the rest of the system?**
  _78 weakly-connected nodes found - possible documentation gaps or missing edges._
- **Should `Community 0` be split into smaller, more focused modules?**
  _Cohesion score 0.06 - nodes in this community are weakly interconnected._
- **Should `Community 1` be split into smaller, more focused modules?**
  _Cohesion score 0.08 - nodes in this community are weakly interconnected._
- **Should `Community 2` be split into smaller, more focused modules?**
  _Cohesion score 0.08 - nodes in this community are weakly interconnected._

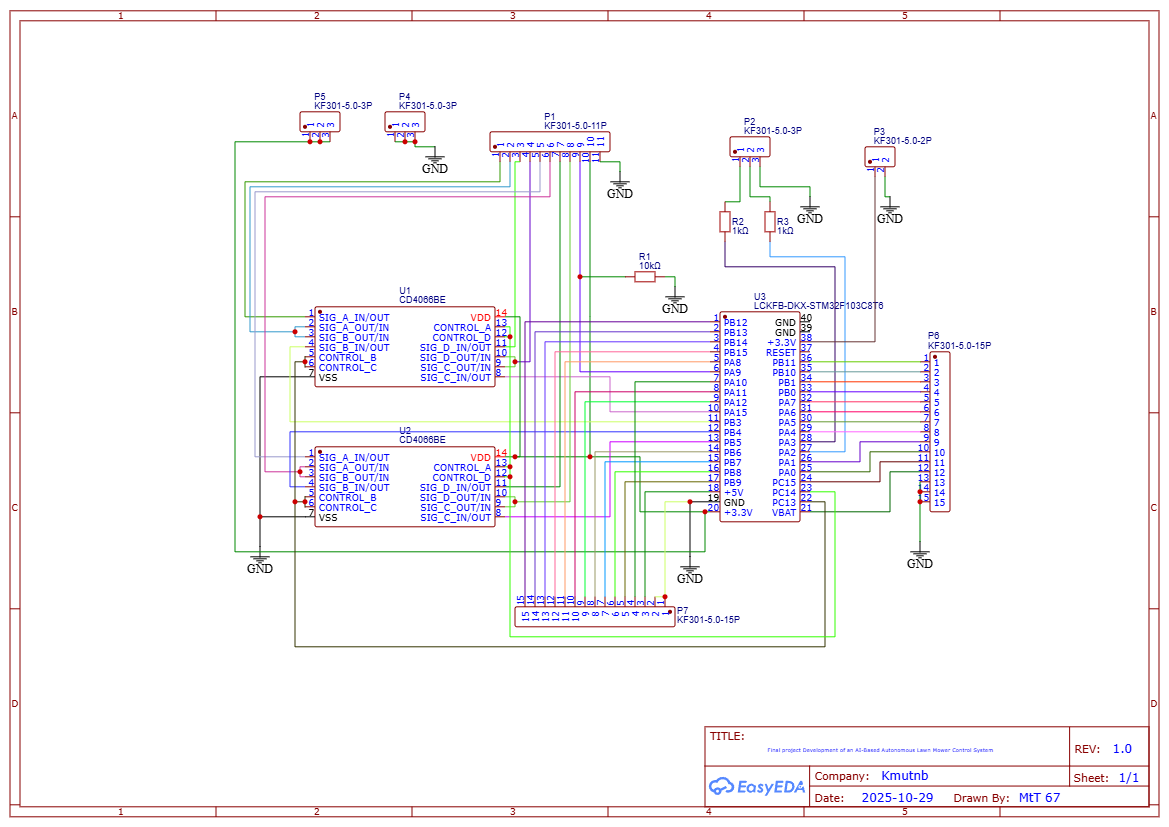
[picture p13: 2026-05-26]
PCB/Schematic_Final-project_2026-05-08.png

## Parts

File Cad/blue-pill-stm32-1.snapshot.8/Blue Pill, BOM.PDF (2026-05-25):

ID Name | Designator | Footprint | Quantity Manufacturer Part | Manufacturer | Supplier Supplier Part Price
1 100nF | C1,C3,C4,C7,C8,C10,C11 0603_1608METRIC_PAD1.05X0.95MM_HANDSOLDER | 7 CL10B104KA8NNNC | SAMSUNG | LCSC | C1590 | 0.003
2 1uF | C2 | 0603_1608METRIC_PAD1.05X0.95MM_HANDSOLDER | 1 CL10A105KO8NNNC | SAMSUNG | LCSC | C1592 | 0.004
3 100uF | C5 | CASE-C_6032 | 1 CA45-C016K107T | Xiangyee | LCSC | C122646 | 0.443
4 330uF | C6 | CASE-C_6032 | 1 CA45-C6R3K337T | Hunan Xiangyee in S&T | LCSC | C201144 | 0.418
5 20pF | C9,C12,C13,C14 | 0603_1608METRIC_PAD1.05X0.95MM_HANDSOLDER | 4 0603CG200J500NT | FH | LCSC | C91702 | 0.004
6 SS110-A | D1 | SMA(DO-214AC) | 1 SS110-A | FMS | LCSC | C143192 | 0.03
7 XL-0603QYGC | LED1,LED2 | LED-0603 | 2 XL-0603QYGC | KENTO | LCSC | C2289
8 HDR-IDC-2.54-2X3P | P1 | HEADER-2.54-P2×3 | 1 2X3 2.54mm IDC Box | BOOMELE | LCSC | C11214 | 0.084
9 SWD | P2 | HEADER-2.54-P4-ANG | 1 Z-211-0411-0021-001 | ZHENGLING | LCSC | C152150 | 0.024
10 210S-1*20P L=11.6MMGold-plated black | P3,P4 | HEADER-2.54-P20 | 2 210S-1*20P L=11.6MMGold-plated black | Ckmtw | LCSC | C124374 | 0.157
11 | 510 R1,R5 | 0603_1608METRIC_PAD1.05X0.95MM_HANDSOLDER | 2 RC0603FR-07510RL | YAGEO | LCSC | C114670 | 0.001
12 10K | R2,R7,R8 | 0603_1608METRIC_PAD1.05X0.95MM_HANDSOLDER | 3 RC0603JR-0710KL | YAGEO | LCSC | C99198 | 0.001
13 100K | R3,R4 | 0603_1608METRIC_PAD1.05X0.95MM_HANDSOLDER | 2 RC0603FR-07100KL | YAGEO | LCSC | C14675 | 0.001
14 1M | R6 | 0603_1608METRIC_PAD1.05X0.95MM_HANDSOLDER | 1 0603WAJ0105T5E | UniOhm | LCSC | C26098 | 0.001
15 | 20 R9,R11 | 0603_1608METRIC_PAD1.05X0.95MM_HANDSOLDER | 2 RS-03K20R0FT | FH | LCSC | C136605 | 0.001
16 1.5K | R10 | 0603_1608METRIC_PAD1.05X0.95MM_HANDSOLDER | 1 0603WAJ0152T5E | UniOhm | LCSC | C25989 | 0.001
17 K2-6639SP-C4SC-04 | RST | KEY-6.0*6.0 | 1 K2-6639SP-C4SC-04 | HRO | LCSC | C83206 | 0.046
18 Micro USB-B 5P_C40942 | U3 | USB-MICROB | 1 Micro USB-B 5P_C40942 | ValuePro | LCSC | C40942 | 0.076
19 AMS1117-3.3 | U8 | SOT-223 | 1 AMS1117-3.3 | AMS | LCSC | C6186 | 0.156
20 8MHz | X1 | OSC-49S-1 | 1 X49SD8MSD2SC | YXC | LCSC | C21263 | 0.07
21 32.768KHz | X2 | MC-306 | 1 X803832768KGD4GI | YXC | LCSC | C12675 | 0.282
22 STM32F103C8T6 | U1 | ST-LQFP48 | 1 STM32F103C8T6 | ST | LCSC | C8734 | 10.023

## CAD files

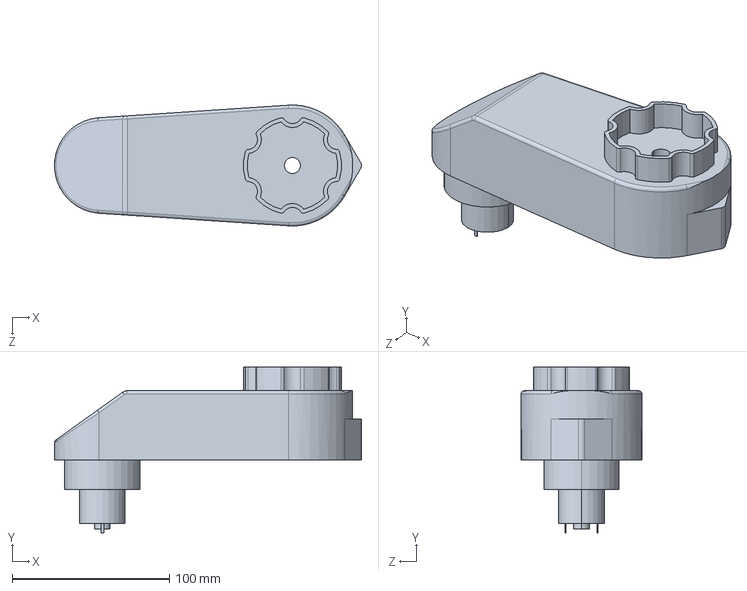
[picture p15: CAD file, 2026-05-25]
Cad/Child motorgear.stp.SLDASM
195.5 x 105.5 x 76.9 mm

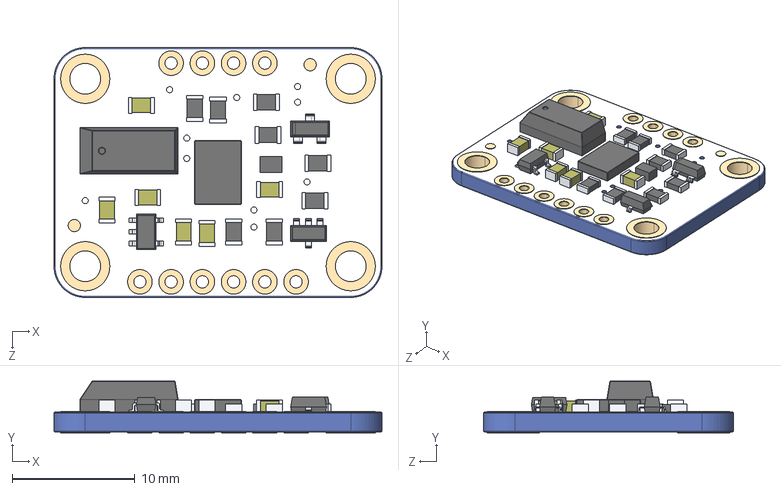
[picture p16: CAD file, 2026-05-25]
Cad/Adafruit BNO055/Adafruit_BNO055_AP214.STEP
26.7 x 4.20 x 20.3 mm

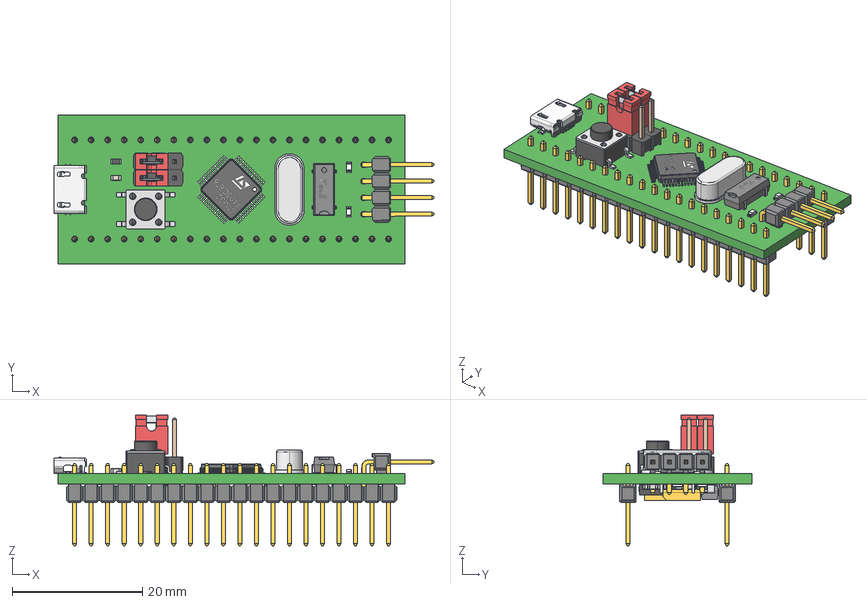
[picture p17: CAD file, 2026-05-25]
Cad/blue-pill-stm32-1.snapshot.8/Blue Pill STM32.step
58.4 x 22.9 x 20.1 mm
Pin1 x 12
Pin2 x 12
CeramicBody x 12
RES0603 x 11
pin_header_1x3_and_jumper x 2
STM32-LQFP48
User_Library-mc-306_crystal
USB_micro
User_Library-LED_SMD0603 x 2
C_6032-28 x 8
User_Library-DO-214AC_SMA
CircuitWorks-SOT-223

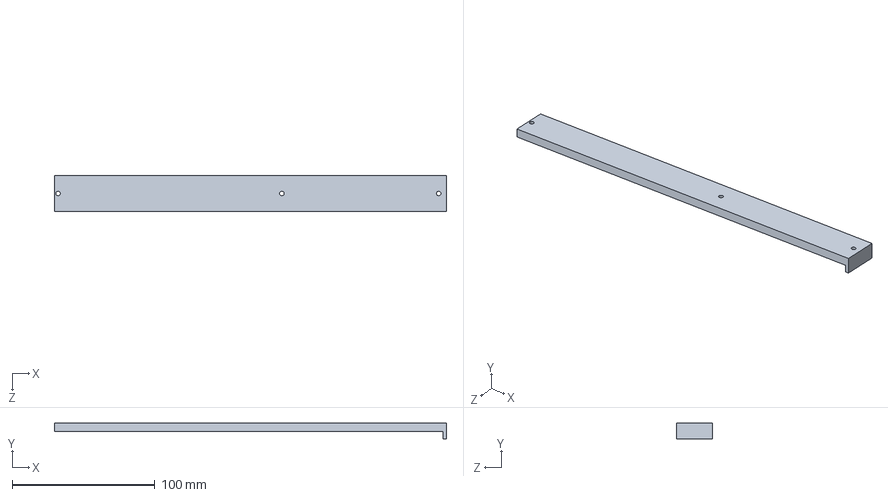
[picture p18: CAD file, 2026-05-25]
Cad/BT/Part3.SLDPRT
275.0 x 11.0 x 25.0 mm

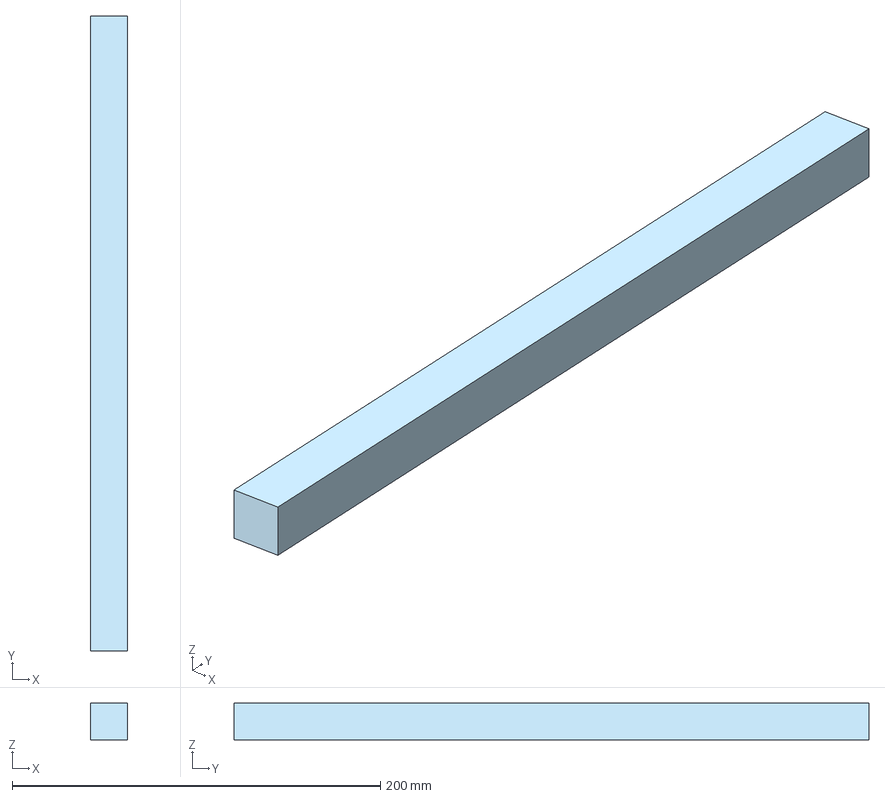
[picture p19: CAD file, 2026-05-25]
Cad/cad/cad/Part Studio 3.step
20.0 x 345.0 x 20.0 mm

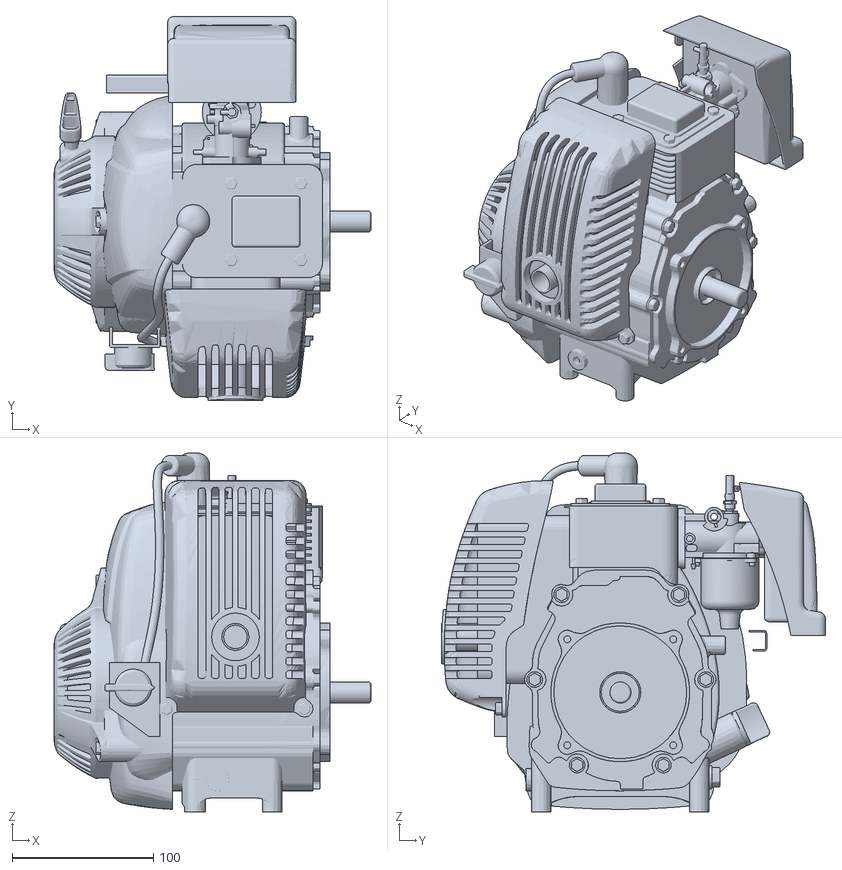
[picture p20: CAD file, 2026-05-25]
Cad/honda-gxh50-engine-1.snapshot.1/HONDA GXH50.stl
223.7 x 271.5 x 253.8

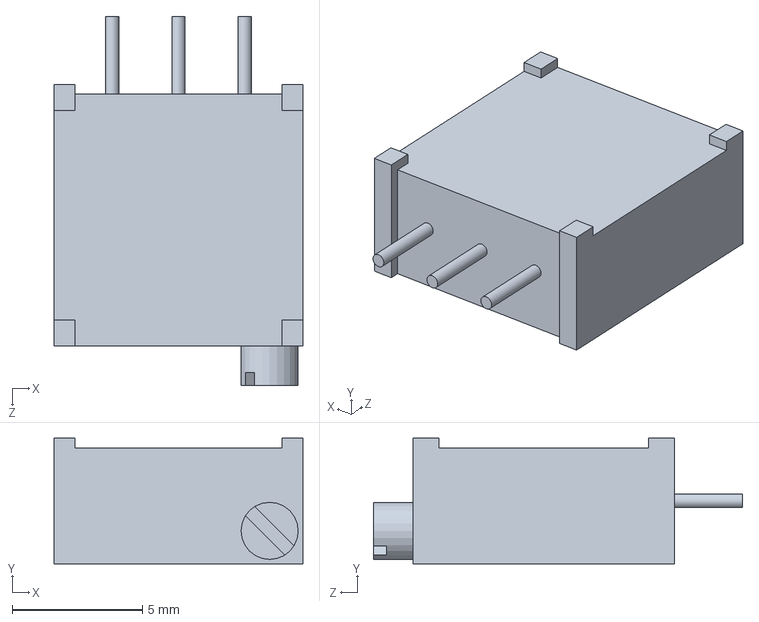
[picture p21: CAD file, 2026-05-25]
Cad/lm2596-buck-converter-4-0-40-to-1-3-37v-adjustable-step-down-power-module-with-led-display-volt-meter-1.snapshot.99/Trimpot 3296W, LM2596 Buck Converter 4.0-40 to 1.3-37V.SLDPRT
9.53 x 4.83 x 14.1 mm

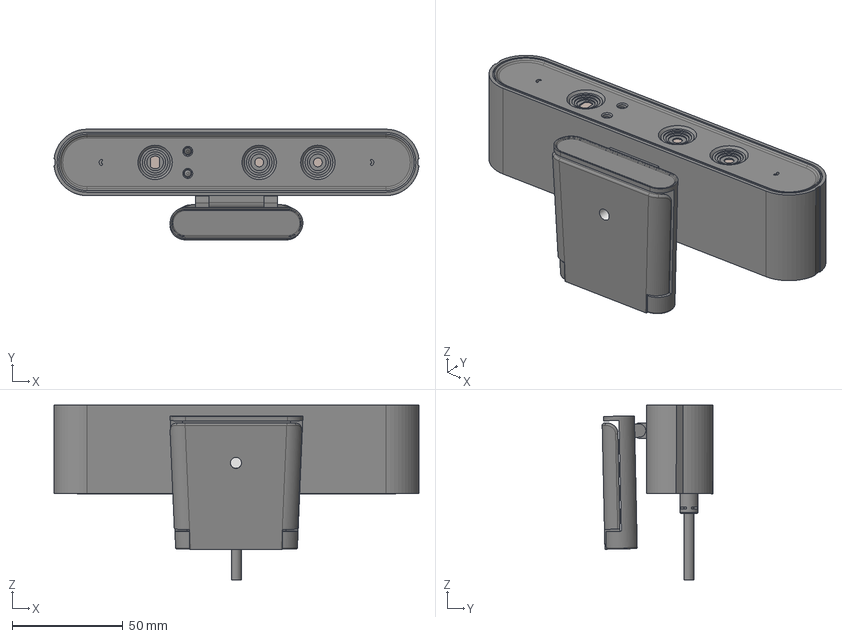
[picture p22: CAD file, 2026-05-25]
Cad/orbbec-astra-s-depth-camera-1.snapshot.3/astra v1.step
164.8 x 50.0 x 78.9 mm
Astra_1
astra_clip1
astra_clip2

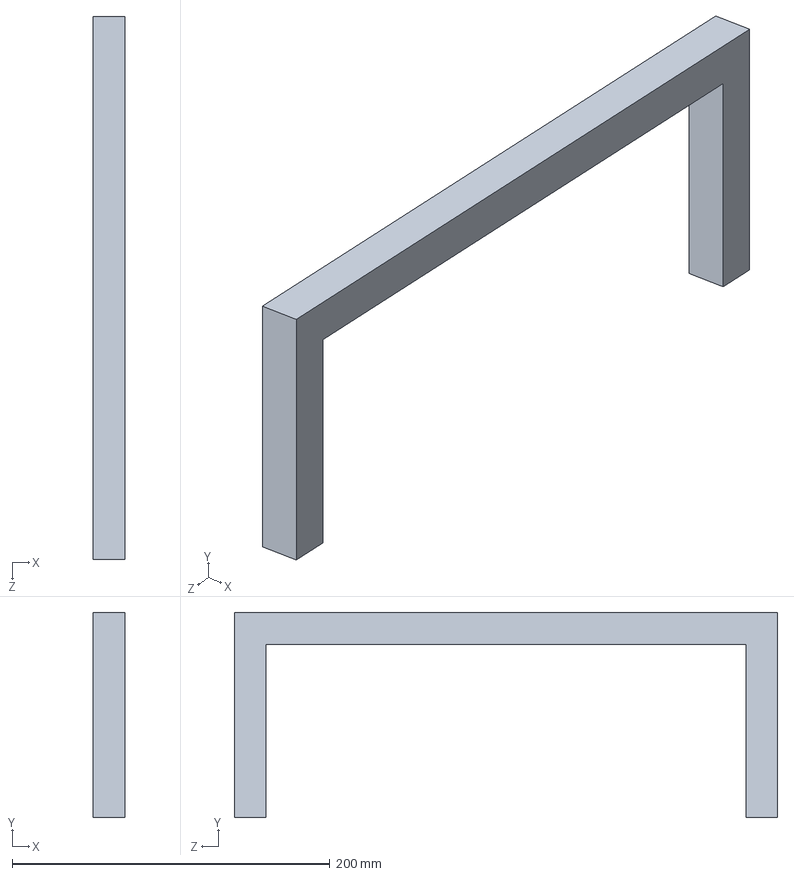
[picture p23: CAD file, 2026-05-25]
Cad/Part3x.SLDPRT
20.0 x 129.0 x 342.0 mm

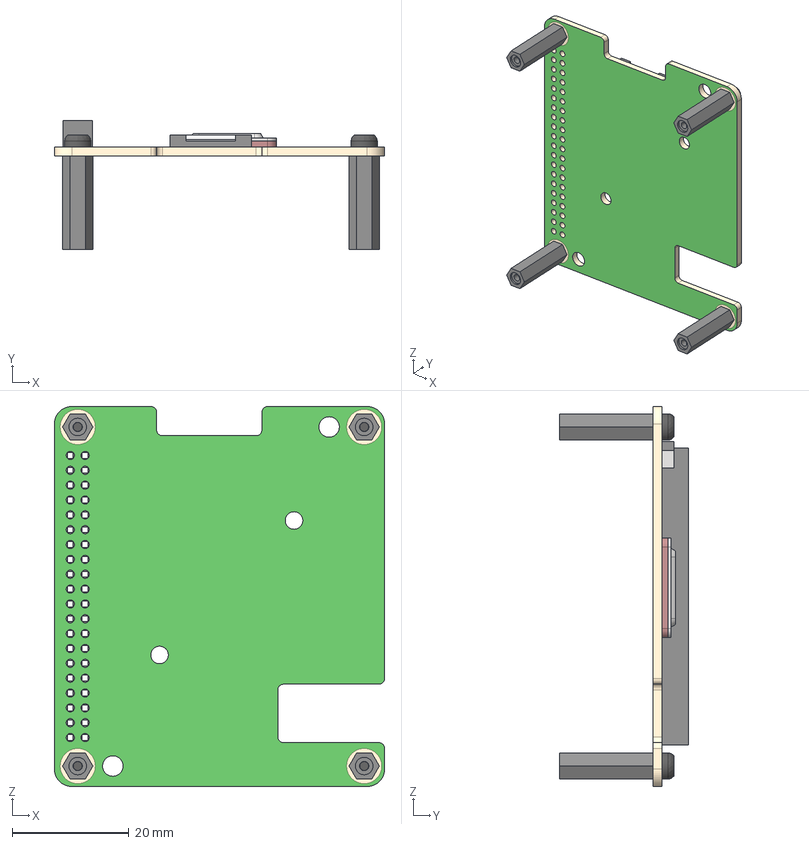
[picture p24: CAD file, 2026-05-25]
Cad/raspberry-pi-ai-hat-1.snapshot.1/RPiAIHATPlus.stp
56.5 x 22.1 x 65.0 mm
RPiAIHATPlusBoard
RPiAIHATPlusLeg x 4
RPiAIHATPlusScrew x 4

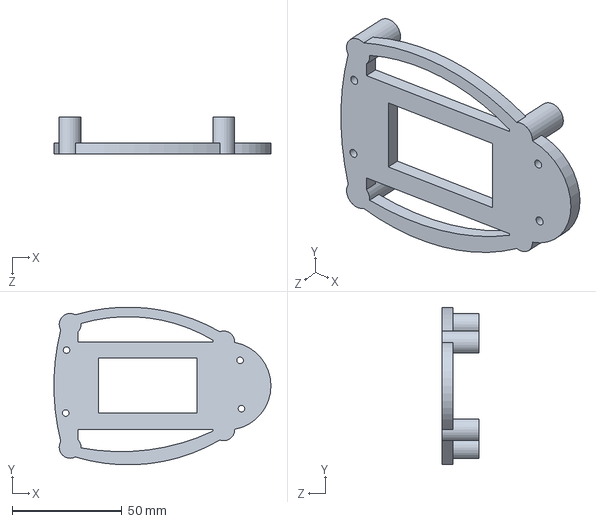
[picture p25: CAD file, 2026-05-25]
Cad/rplidar-a1-holder-1.snapshot.2/lidar holder/Part22.SLDPRT
98.9 x 71.8 x 17.0 mm

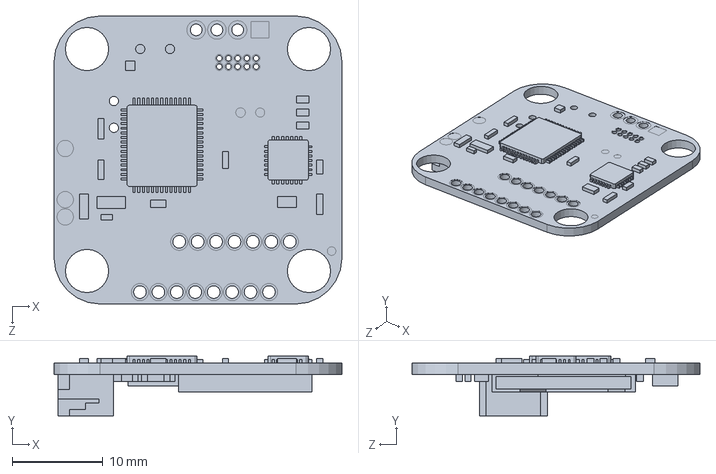
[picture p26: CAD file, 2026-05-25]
Cad/sparkfun-9dof-razor-inertial-measurement-unit-imu-m0-1.snapshot.1/Sparkfun 9Dof IMU.SLDPRT
31.8 x 6.60 x 31.8 mm

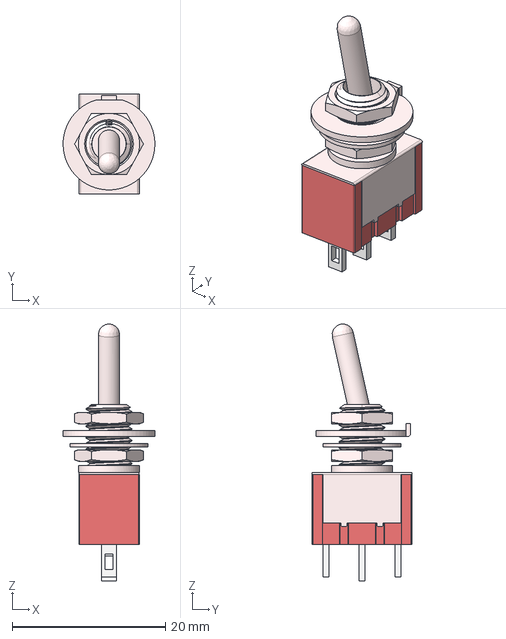
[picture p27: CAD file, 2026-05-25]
Cad/toggle-switch-19.snapshot.2/Toggle Switch SPDT Panel Mount.stp
12.0 x 13.0 x 33.6 mm

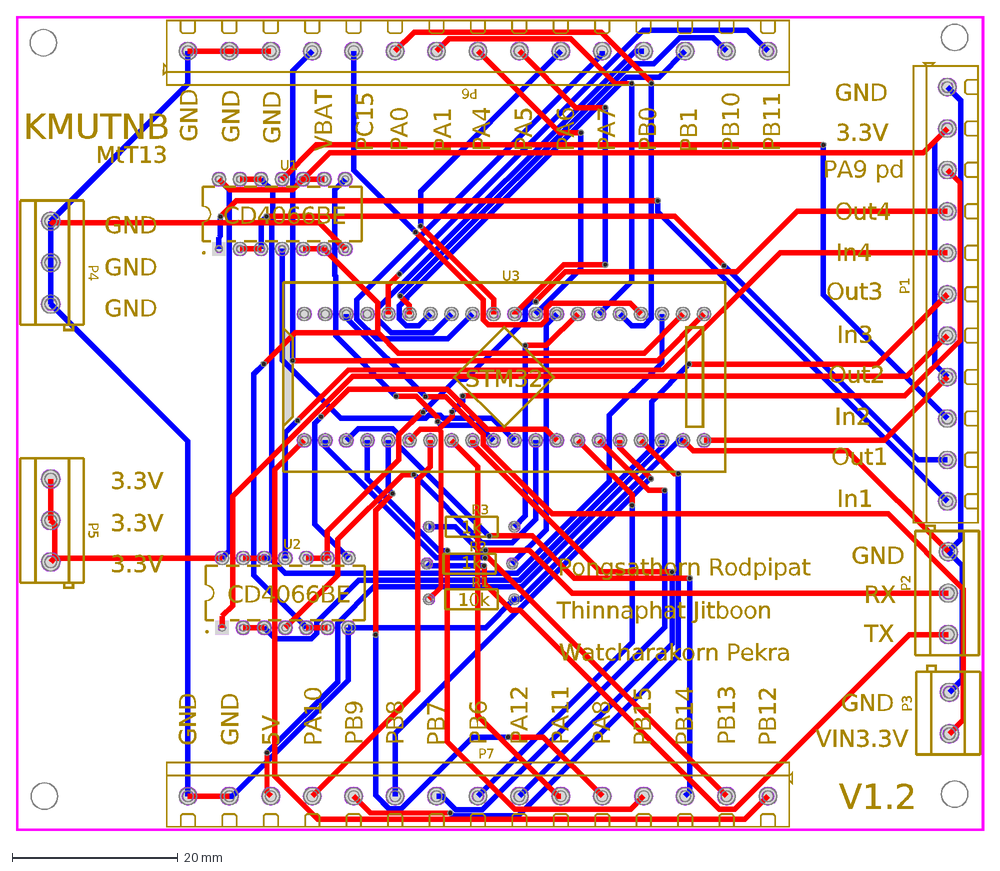
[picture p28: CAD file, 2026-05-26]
PCB/PCB_Final-project_2_2026-05-26.dxf
GND
3.3V
PA9 pd
Out4
In4
Out3
In3
Out2
In2
Out1
In1
RX
TX
VIN3.3V
5V
PA10
PB9
PB8
PB7
PB6
PA12
PA11
PA8
PB15
PB14
PB13
PB12
PC15
VBAT
PA0
PA1
PA4
PA5
PA6
PA7
PB0
PB1
PB10
PB11
MtT13
Pongsathorn Rodpipat
Watcharakorn Pekra
Thinnaphat Jitboon
STM32
KMUTNB
CD4066BE
V1.2
10k
1k
R2
R3
P1
P2
P4
P5
P3
P6
P7
R1
U1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

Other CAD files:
Cad/BT/AssemBT1.SLDASM
Cad/rplidar-a1-holder-1.snapshot.2/RP-lidar-A1.igs.STEP.SLDASM
Cad/motor-gear-toy-car-1.snapshot.2/Child motorgear.stp
Cad/rplidar-a1-holder-1.snapshot.2/bottom-lid.igs.STEP.SLDPRT
Cad/100mm.SLDPRT
Cad/160mm.SLDPRT
Cad/Adafruit BNO055/Adafruit_BNO055.SLDPRT
Cad/Adafruit BNO055/Adafruit_BNO055_AP203.STEP
Cad/BT/Part1.SLDPRT
Cad/BT/Part1.STL
Cad/BT/Part2.SLDPRT
Cad/BT/p1.SLDPRT
Cad/BT/p1.STL
Cad/BT/p2.SLDPRT
Cad/BT/p2.STL
Cad/Battery.SLDPRT
Cad/Part12.SLDPRT
Cad/Part14.SLDPRT
Cad/Part19.SLDPRT
Cad/Part2.SLDPRT
Cad/Part3.STEP
Cad/Part4.2.SLDPRT
Cad/Part4.SLDPRT
Cad/Part5.1.SLDPRT
Cad/Part5.2.SLDPRT
Cad/Part5.SLDPRT
Cad/Track2.SLDPRT
Cad/Track_83mm.SLDPRT
Cad/blue-pill-stm32-1.snapshot.8/Blue Pill STM32.dwg
Cad/cad/cad/Part Studio 1.step
Cad/cad/cad/Part Studio 2.step
Cad/cad/cad/Part Studio 5.step
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

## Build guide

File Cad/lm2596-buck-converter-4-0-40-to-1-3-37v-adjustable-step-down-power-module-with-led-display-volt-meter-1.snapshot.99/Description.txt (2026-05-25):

LM2596 Buck Converter 4.0~40 to 1.3-37V Adjustable Step-Down Power Module with LED Display Volt meter

Link to CAD file:
https://grabcad.com/library/lm2596-buck-converter-4-0-40-to-1-3-37v-adjustable-step-down-power-module-with-led-display-volt-meter-1

#CAD #SolidWorks #3dmodel #buckconverter #stepdownbuckconverter #LM2596

Input voltage:4.0V-40V

Output voltage:1.25V～37V

Voltage regulation ± 2.5%

Switching frequency:150KHz

Conversion efficiency: 92%(highest),
Load regulation ±0.5%

Max Electric current: 3A
Normal working electric current: 2A

150KHz Internal oscillation frequency
Low power consumption
High efficiency

Buy Links:
https://www.aliexpress.us/item/2251832392854599.html

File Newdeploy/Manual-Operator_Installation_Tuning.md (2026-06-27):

# 📚 คู่มือการติดตั้ง ปฏิบัติงาน  และจูนระบบหุ่นยนต์ตัดหญ้าอัตโนมัติ

*(Autonomous Lawn Mower Complete Manual: Operator, Installation & Tuning Guide)*

คู่มือฉบับนี้ได้รับการจัดเรียงลำดับหมวดหมู่เพื่อให้ง่ายต่อการอ่านศึกษา และพร้อมสำหรับส่งมอบงานต่อให้ผู้พัฒนาระบบคนถัดไป โดยแบ่งออกเป็น 3 ส่วนหลักอย่างเป็นระบบ:

1. [**ส่วนที่ 1: คู่มือผู้ควบคุมระบบหน้างาน (Operator Manual)**](#🚜-ส่วนที่-1:-คู่มือผู้ควบคุมระบบหน้างาน-\(operator-manual\))  
2. [**ส่วนที่ 2: คู่มือการติดตั้งและการตั้งค่าระบบ (Developer Installation & Surveying Guide)**](#💻-ส่วนที่-2:-คู่มือการติดตั้งและการใช้งานระบบ-\(developer-installation-&-usage-guide\))  
3. [**ส่วนที่ 3: คู่มือการจูนระบบและการวิเคราะห์สถาปัตยกรรมเชิงลึก (System Tuning & Deep Diagnostic Guide)**](#🛠️-ส่วนที่-3:-คู่มือการจูนระบบและการวิเคราะห์สถาปัตยกรรม-\(system-tuning-&-diagnostic-guide\))

# 

# 🚜 ส่วนที่ 1: คู่มือผู้ควบคุมระบบหน้างาน  (Operator Manual) {#🚜-ส่วนที่-1:-คู่มือผู้ควบคุมระบบหน้างาน-(operator-manual)}

คู่มือสำหรับการใช้งานทั่วไปในแต่ละวัน การควบคุมรถตัดหญ้าผ่านโหมดต่างๆ และการดูแลรักษาความปลอดภัยขั้นต้น

## 

## 1\. การควบคุมผ่านรีโมทคอนโทรล

* **1.1** สวิตช์ที่ 1 ใช้สำหรับสลับโหมด  
* **1.2** สวิตช์ที่ 2 ใช้สำหรับสสตาร์ทเครื่องยนต์  
* **1.3** คันโยกที่ 1 ใช้สำหรับเร่งเครื่องยนต์  
* **1.4** คันโยกที่ 2 ใช้สำหรับควบคุมทิศทางของรถ

## 2\. การชาร์จแบตเตอรี่

* **2.1** เสียบสายชาร์จเข้ากับช่องรับสายชาร์จของตัวเครื่อง  
* **2.2** กด ปุ่มหยุดฉุกเฉิน ค้างไว้ และเปิด สวิตช์ Power  
* **2.3** สังเกตไฟสถานะที่เครื่องชาร์จจะแสดงเป็น สีแดง และตัวเลขบอกค่าแรงดันไฟฟ้าที่หน้าจอมิเตอร์จะเพิ่มสูงขึ้น  
* **2.4** เมื่อชาร์จไฟจนเต็มระบบ ไฟสถานะที่เครื่องชาร์จจะเปลี่ยนเป็น สีเขียว

## 3\. การทำงานแบบ Manual mode

* **3.1** หมุนเพื่อปลด ปุ่มหยุดฉุกเฉิน  
* **3.2** เปิดสวิตช์การทำงานหลัก เพื่อจ่ายกระแสไฟให้ระบบควบคุมและชุดขับเคลื่อน  
* **3.3** เปิดสวิตช์กล่องควบคุมและเปิดการทำงานของรีโมท  
* **3.4** สังเกตุไฟสถานะที่กล่องควบคุมต้องไม่ติด (Manual mode) ถ้าไฟสถานะติดให้โยกสวิตช์เลือกโหมดไปอีกด้าน  
* **3.5** ทดสอบและบังคับทิศทางของตัวเครื่อง (เดินหน้า ถอยหลัง เลี้ยวซ้าย ขวา)

## 4\. การทำงานแบบ Auto mode

* **4.1** ตรวจสอบให้แน่ใจว่าแบตเตอรี่มีพลังงานเพียงพอ และน้ำมันเชื้อเพลิงอยู่ในระดับที่เหมาะสม  
* **4.2** วาง RTK Base Station ในตำแหน่งที่มีสัญญาณดาวเทียมชัดเจน และเปิดการทำงาน  
* **4.3** เปิด Laptop และเชื่อมต่อ Wi-Fi เข้ากับระบบของรถ  
* **4.4** เปิดโปรแกรม ROS2 บน Laptop ด้วยคำสั่ง:  
    
  `cd ros2_ws`  
  `source install/setup.bash`  
  `./start_robot.sh`  
    
* **4.5** กำหนดขอบเขตพื้นที่ตัดหญ้า (Boundary) และ Waypoint บนโปรแกรม RViz  
* **4.6** โยกสวิตช์เลือกโหมดไปที่ Auto mode สังเกตไฟสถานะที่กล่องควบคุมต้องติด  
* **4.7** พิมพ์ “ go ” บนโปรแกรมเพื่อเริ่มการทำงานอัตโนมัติ  
* **4.8** สังเกตการทำงานของรถ ระบบจะวิ่งตามเส้นทางที่กำหนดโดยอัตโนมัติ และหยุดเองเมื่อครบพื้นที่

## 

## 5\. ระบบความปลอดภัย

* **5.1** ปุ่มหยุดฉุกเฉิน (Emergency Stop) — กดปุ่มแดงบนตัวเครื่องเพื่อหยุดระบบทันทีในกรณีฉุกเฉิน  
* **5.2** ระบบตรวจจับสิ่งกีดขวาง — LiDAR จะตรวจจับและหยุดรถอัตโนมัติเมื่อมีสิ่งกีดขวางในระยะ 1 เมตร  
* **5.3** ระบบหยุดอัตโนมัติเมื่อออกนอกพื้นที่ที่กำหนด  
* **5.4** ตรวจสอบพื้นที่ให้ปราศจากสิ่งกีดขวางขนาดเล็กที่ LiDAR อาจตรวจไม่พบ เช่น สายไฟ ก้อนหิน ก่อนเริ่มใช้งาน

## 6\. การดับเครื่องและเก็บรักษา

* **6.1** โยกสวิตช์เลือกโหมดกลับไปที่ Manual mode  
* **6.2** ปิดสวิตช์กล่องควบคุมและปิด Laptop  
* **6.3** กดปุ่มหยุดฉุกเฉินเพื่อตัดกระแสไฟฟ้าทั้งหมด  
* **6.4** ปิดสวิตช์ Power หลัก  
* **6.5** ถอดสายชาร์จ (ถ้ามี) และทำความสะอาดตัวเครื่องหลังใช้งาน  
* **6.6** เก็บรถในที่ร่ม แห้ง และปลอดภัยจากฝนและความชื้น

---

# 

# 💻 ส่วนที่ 2: คู่มือการติดตั้งและการใช้งานระบบ (Developer Installation & Usage Guide) {#💻-ส่วนที่-2:-คู่มือการติดตั้งและการใช้งานระบบ-(developer-installation-&-usage-guide)}

คู่มือขั้นตอนทางเทคนิคสำหรับเริ่มติดตั้งระบบบนคอมพิวเตอร์ใหม่ การจูนโครงสร้างพื้นฐาน และการสำรวจแนวเขตสนาม

## 1\. ขั้นตอนการติดตั้งโปรแกรมเริ่มจาก Ubuntu 22.04  (Fresh Installation)

### ขั้นตอนที่ 1.1: วิธีการนำไฟล์โปรเจคเข้ามาในเครื่อง

#### วิธีที่ A: การดาวน์โหลดไฟล์บีบอัด (.ZIP)

1. ทำการบีบอัดโฟลเดอร์โปรเจค `ros2_ws` จากเครื่องทดสอบเดิมเป็นไฟล์ `ros2_ws.zip` (โดยลบโฟลเดอร์ที่ไม่จำเป็นอย่าง `build`, `install`, `log` ออกก่อนเพื่อลดขนาดไฟล์)  
2. นำไฟล์ ZIP ไปคลายตัว (Extract) ลงบนเครื่องใหม่ไว้ที่พาธโฟลเดอร์หน้าหลัก (Home Directory): `/home/<ชื่อผู้ใช้ใหม่>/`  
3. เปลี่ยนชื่อโฟลเดอร์ เช่น: `ros2_ws`

#### วิธีที่ B: การดึงผ่านระบบ Git:

`sudo apt update && sudo apt install git -y`

mkdir \-p \~/ros2\_ws && cd \~/ros2\_ws

`git clone https://github.com/Bank6452/Development-of-an-AI-Based-Autonomous-Lawn-Mower-Control-System.git .`

---

### ขั้นตอนที่ 1.2: การติดตั้ง ROS2 Humble และ Dependencies

หลังจากได้โฟลเดอร์ `~/ros2_ws` มาอยู่ในเครื่องแล้ว ให้เรียกใช้สคริปต์ติดตั้งตามลำดับต่อไปนี้:

1. **เข้าโฟลเดอร์โปรเจค:**  
     
   `cd ~/ros2_ws`  
     
2. **จัดการสิทธิ์ในการเข้าใช้พอร์ต USB:**  
     
   `sudo usermod -aG dialout $USER`  
     
   *(หมายเหตุ: ต้องทำการปิด Terminal แล้วเปิดใหม่ หรือ Reboot เครื่อง เพื่อให้สิทธิ์มีผล)*  

3. **ติดตั้งระบบปฏิบัติการหุ่นยนต์ ROS2 Humble:** ให้เปิดใช้งานสิทธิ์การเรียกใช้สคริปต์ และสั่งเรียกใช้ตัวติดตั้งอัตโนมัติ:  
     
   `chmod +x install_ros2_humble.sh`  
     
   `./install_ros2_humble.sh`  
     
4. **สร้าง Python Environment:**

   `python3 -m venv venv --system-site-packages`  
   `source venv/bin/activate`  
     
5. **ติดตั้งแพ็คเกจเสริมที่หุ่นยนต์ต้องใช้:**  
     
   `chmod +x install_dependencies.sh`  
     
   `./install_dependencies.sh`  
     
   *(สคริปต์นี้จะลงทะเบียนไลบรารีนำทาง Nav2, ตัวคำนวณ EKF, และไลบรารีใน Python เช่น numpy=1.23.5 และ shapely ให้พร้อมใช้ทันที)*  
   รายการLibrary ที่จำเป็น อยู่ในไฟล์ `~/ros2_ws/requirements.txt`  
     
6. **คอมไพล์โค้ดโปรเจค (Colcon Build):**  
     
   `source /opt/ros/humble/setup.bash`  
   `colcon build --symlink-install`

---

## 2\. การตั้งค่าต่างๆ (System Configurations Setup)

### A. การระบุค่าพิกัดอ้างอิงและ NTRIP สำหรับ GPS RTK

* **ไฟล์ตั้งค่า:** `~/ros2_ws/src/robot_bridge/config/ntrip_params.yaml`  
* **ข้อมูลที่ต้องกรอกสำหรับย้ายสนาม:**  
  * **ip:** ไอพีของ Server สถานีฐานอ้างอิงพิกัด   
  * **port:** พอร์ตที่เข้าใช้งาน (เช่น 2116\)  
  * **mountpoint:** รูปแบบการแปลงสัญญาณ (เช่น VRS\_RTCM32)  
  * **user & password:** ข้อมูลบัญชีผู้ใช้งานที่ใช้รับสัญญาณ

---

## 

## 3\. การสำรวจขอบเขตสนามตัดหญ้า (Field Surveying Instruction) **\*\* สามารถข้ามไป ทำพร้อมข้อถัดไปได้เลย\*\***

นี่คือคู่มือในการพาหุ่นยนต์เดินสแกนเพื่อสร้างขอบเขตรั้วความปลอดภัย เพื่อไม่ให้ล้อหลุดตกลงไปในแปลงดอกไม้หรือสระน้ำ

### ขั้นตอนปฏิบัติหน้างาน:

1. **เตรียมหุ่นยนต์ให้พร้อม:** นำหุ่นไปวางในจุดเริ่มต้นที่เรียบในสนาม  
2. **เรียกใช้ตัวคุมรั้วในโหมด Teach-in:**  
     
   `ros2 run robot_bridge geofence_enforcer`  
     
   *หน้าจอจะแสดงทางเลือก ให้พิมพ์เลือกหมายเลข **`2` (สร้างรั้วใหม่ / Teach-in)** แล้วกด Enter*  
     
3. **การบังคับบันทึกจุด:**  
   * ใช้คีย์บอร์ดหรือคอนโทรลเลอร์ควบคุมขับหุ่นยนต์ช้าๆ ไปยังมุมแรกของสนามหยุดนิ่ง แล้วกด **\[Enter\]** ที่ PC เพื่อบันทึกจุดมุมที่ 1  
   * ขับต่อไปยังมุมถัดไปและกด **\[Enter\]** เพื่อบันทึกมุมถัดไปเรื่อยๆ จนกระทั่งเดินครบรอบรูปทรงสนาม  
4. **การเซฟบันทึกขอบเขต:**  
   * เมื่อวนครบรอบและเก็บจุดมุมทั้งหมดเรียบร้อยแล้ว ให้พิมพ์ตัวอักษร **`s`** ใน Terminal แล้วกด **\[Enter\]**  
   * โปรแกรมจะประมวลผลเซฟพิกัดลงไฟล์ `lawn_geofence.yaml`  
   * **กลไก Datum อัตโนมัติ:** ระบบจะตั้งจุดเริ่มต้นจุดแรกให้เป็นค่า Datum 0,0 ของพิกัดแผนที่ (Local map) โดยอัตโนมัติ ทำให้ผู้ใช้ไม่ต้องไปตั้งค่าเองเมื่อสลับสนามใหม่

---

## 4\. การเปิดใช้งานเครื่องและสั่งตัดหญ้าจริง (Mower Operations)

ขั้นตอนการเรียกใช้โปรแกรมระบบอัตโนมัติทั้งหมดเพื่อปฏิบัติงานและบังคับการตัดหญ้าจริง

### ขั้นตอนปฏิบัติการ:

**\[ลำดับสำคัญที่สุด\]** ทำการเปิดใช้สัญญาณแก้พิกัดดาวเทียม RTK (NTRIP Client):  
เปิด Terminal แท็บแยกเพื่อใช้สคริปต์รับพิกัดแก้ผ่านเครือข่ายอินเทอร์เน็ต ทิ้งไว้ตลอดเวลาการทำงาน

`cd ~/ros2_ws && source install/setup.bash`  
`./start_ntrip.sh`

1. **เรียกใช้คำสั่งเริ่มระบบหุ่นยนต์หลัก:**  
   **คำสั่งเพิ่มเติมอยู่ในไฟล์Command (\~/ros2\_ws/command.txt)**

   `cd ~/ros2_ws`  
   `source install/setup.bash`  
   `./start_robot.sh`  
     
   *สคริปต์จะทำการเปิดโปรแกรมทั้งหมดขึ้นมาแยกออกเป็น 6 แท็บโดยอัตโนมัติ พร้อมทั้งเรียกใช้ระบบ EKF Sensor Fusion เพื่อล็อกศูนย์ตำแหน่งกับจุด Datum ที่บันทึกไว้ในขั้นตอนสำรวจสนาม*  
     
2. **การทำงานของระบบ Safety:**  
   * ระหว่างที่หุ่นตัดหญ้าเคลื่อนที่ โหนด `geofence_enforcer` (แท็บที่ 4\) จะใช้ไลบรารี `shapely` เปรียบเทียบตำแหน่งเมตร X, Y ของหุ่นเทียบกับแนวรั้วในไฟล์สนามจริงตลอดเวลาที่ความถี่ 10Hz  
   * **หากหุ่นล้ำออกนอกเขต:** จะส่งสัญญาณ `1` ไปที่ Topic `/emergency_stop` ซึ่งจะทำให้โหนด `teleop_stm.py` บล็อกสัญญาณควบคุมความเร็วล้อ ล้อจะล็อกหยุดทำงานทันทีเพื่อความปลอดภัยสูงสุด  
       
3. **การสั่งตัดหญ้าอัตโนมัติ (Mowing Execute):**  
   * ไปที่แท็บชื่อ **`5. MOWING`**  
   * รอจนกระทั่งระบบเช็คความมั่นใจพิกัดนิ่งดีแล้ว  
   * พิมพ์คำสั่ง **`go`** แล้วกด **\[Enter\]**  
   * หุ่นยนต์จะเริ่มกระบวนการคำนวณเส้นทางการเดินตัดหญ้าแบบซิกแซก (Coverage Path Planning) และเริ่มเคลื่อนไหวปฏิบัติงานโดยสมบูรณ์

---

*หากในระหว่างการใช้งาน TerminalTabs พัง สามารถใช้สคริปส์เหล่านี้สั่งทำงานซ้ำใน Tab ที่พังได้*

* **Tab 1:** `ros2 launch robot_bridge hardware_bringup.launch.py`  
* **Tab 2:** `ros2 launch robot_bridge localization.launch.py`  
* **Tab 3:** `ros2 launch robot_bridge navigation.launch.py`  
* **Tab 4:** `ros2 run robot_bridge geofence_and_planner`  
* **Tab 5:** `ros2 run robot_bridge mow_zigzag`  
* **Tab 6:** `ros2 run robot_bridge robot_dashboard`

---

## 

## 5\. การทำงานบนระบบจำลองเสมือนจริง (Gazebo Simulation Operations) ในไฟล์

ขั้นตอนการเรียกใช้โปรแกรมระบบจำลองเชิงฟิสิกส์ 3 มิติเพื่อทดสอบคำสั่งและการวางแผนเส้นทางนำทางของตัวหุ่นยนต์อย่างปลอดภัย:

### ขั้นตอนปฏิบัติการจำลอง:

1. **เรียกใช้คำสั่งเริ่มระบบจำลองหุ่นยนต์:**  
     
   `cd ~/ros2_ws`  
   `./start_sim.sh`  
     
   *สคริปต์จำลองจะเคลียร์หน่วยความจำเก่าโดยการสั่งหยุดกระบวนการเดิมทั้งหมดด้วย `pkill` และ `killall` จากนั้นจะทำความสะอาดระบบ สร้าง/ประกอบโค้ดระบบใหม่ผ่าน `colcon build --symlink-install` และเปิดส่วนประกอบต่างๆ ขึ้นมาโดยอัตโนมัติ:*  
     
   * **ระบบจำลองฟิสิกส์ (Gazebo Simulation) ในไฟล์:** จำลองสภาพแวดล้อมสนามและน้ำหนักล้อเหมือนจริงผ่านโมเดล `mower_gazebo.xacro` และไฟล์เวิลด์ `my_obstacle_world.world`  
   * **ระบบระบุพิกัดและแผนที่นำทาง (Nav2 & EKF) ในไฟล์:** ดึงค่าตั้งค่าจำลองจาก `ekf_sim.yaml`  
   * **ระบบวางแผนเส้นทางและ geofence ในไฟล์:** คำนวณเส้นทางเดินซิกแซกโดยดึงค่าพิกัดสนามหญ้าจำลองจาก `lawn_geofence_sim.yaml`  
2. **การตอบสนองเมื่อตัวรถเบี่ยงเบนออกนอกเส้นทางจำลอง ในไฟล์:**  
   * **การคำนวณระยะเยื้องศูนย์สะสม (Cross-Track Error):** โหนดติดตามภารกิจ `mow_zigzag.py` จะคำนวณระยะห่างเพื่อหาค่าเบี่ยงเบนสูงสุด (Max Deviation) บันทึกรายงานภารกิจลงรายงาน HTML ในโฟลเดอร์ `~/mower_reports/`  
   * **การปรับเลี้ยวกลับเข้าทาง (DWB Local Planner Steering):** เมื่อทิศทางเฉออก ปลั๊กอินควบคุมความเร็วล้อจะปรับชดเชยการเลี้ยวโดยอัตโนมัติเพื่อนำหัวหุ่นยนต์กลับเข้าแนวเส้นทาง  
   * **โหมดกู้คืนระบบนำทาง (Nav2 Recovery Behaviors):** สถาปัตยกรรม Nav2 จะเข้าสู่โหมดกู้คืน (Recovery) เพื่อถอยหลังหรือหมุนตัวเลี่ยงการค้างชั่วขณะโดยอัตโนมัติ

# 

# 🛠️ ส่วนที่ 3: คู่มือการจูนระบบและการวิเคราะห์สถาปัตยกรรม  (System Tuning & Diagnostic Guide) {#🛠️-ส่วนที่-3:-คู่มือการจูนระบบและการวิเคราะห์สถาปัตยกรรม-(system-tuning-&-diagnostic-guide)}

คู่มือวิชาการเชิงลึกสำหรับนักพัฒนา เพื่ออธิบายกลไกการรับส่งข้อมูลใน ROS2 การจูนพารามิเตอร์เซ็นเซอร์ และคำสั่งสำหรับการตรวจจับวิเคราะห์ข้อผิดพลาด

## 1\. โครงสร้างการทำงานของพารามิเตอร์ใน ROS 2  (Launch vs. ไฟล์รอง Python)

**ลำดับความสำคัญของพารามิเตอร์** ที่ซับซ้อนในหุ่นยนต์คันนี้มีดังนี้:

* **ไฟล์หลัก (`hardware_bringup.launch.py`):** เป็นหน้าด่านหลักในการเรียกใช้ระบบ หากมีตัวแปรใดตั้งค่าไว้ในไฟล์นี้ **ระบบจะยึดถือค่านี่เป็นหลัก (Override) และเพิกเฉยค่าดั้งเดิมในไฟล์รองไปเลยทันที**  
* **ไฟล์รอง (ไฟล์โค้ด Python/C++ เช่น `vision_node.py` หรือ `teleop_stm.py`):** เป็นจุดประกาศตัวแปรเริ่มต้น มีไว้เพื่อความปลอดภัย **"กันหลุด" (Safety Fallback)** หากไฟล์หลักไม่มีการประกาศค่าจูน หรือระบบสัญญาณหลุด โค้ดจะดึงค่าเริ่มต้นในนี้มาใช้นำทางเพื่อป้องกันหุ่นยนต์ชนอุบัติเหตุ  
* **ข้อกำหนดสำคัญ:**  
  * ตัวแปรใดที่ระบุหรือไฮไลต์ว่า **\[จูนผ่านไฟล์ Launch ได้\]** ➡️ ให้แก้ไขที่ไฟล์ Launch เพียง **จุดเดียว** เท่านั้น ห้ามไปแก้ในไฟล์รอง (เพราะจะไม่มีผลอะไรเมื่อเรียกใช้จริง)  
    **`@~/ros2_ws/src/robot_bridge/launch`**  
      
  * ตัวแปรใดที่ระบุหรือไฮไลต์ว่า **\[จูนในไฟล์รอง (Python) เท่านั้น\]** ➡️ แปลว่าตัวแปรนั้นไม่ได้ทำระบบรับค่าผ่าน ROS 2 Parameter ไว้ ผู้พัฒนาต้องเปิดไฟล์ Python เข้าไปแก้บรรทัดโค้ดโดยตรงจึงจะมีผลหน้างาน  
    **`@~/ros2_ws/src/robot_bridge/robot_bridge`**

## 2\. วิธีการบายพาสระบบความปลอดภัย (Safety Bypass Guide)

**Bypass (ข้ามการตรวจเช็คระบบความปลอดภัยจาก LiDAR และ AI Vision D435i)** ได้ดังนี้:  
พารามิเตอร์ **`bypass_safety`** (เริ่มต้นเป็น `False`) ถูกประกาศใช้งานในโหนด **teleop\_stm.py**

| teleop\_stm.py  |
| :---- |
| `self.declare_parameter('bypass_safety', False)` |

* **เมื่อปิด Bypass (`False`):** ระบบจะหยุดการสั่งมอเตอร์ทันทีหาก `lidar_safe` หรือ `vision_safe` เป็น `False` (ตรวจเจอวัตถุ / กล้อง AI ค้าง)  
* **เมื่อเปิด Bypass (`True`):** ระบบจะบังคับตัวแปร `is_safe = True` ตลอดเวลา และเซ็ตให้ `self.vision_safe = True` ทันทีโดยไม่สนใจสิ่งกีดขวาง

## 3\. ขอบเขตการทำงานของเลเซอร์วัดระยะ  (LiDAR Field of View Boundary)

ระบบความปลอดภัยขั้นต้นใช้สแกนรอบทิศทาง **RPLiDAR A1** แต่เนื่องจากตัวบอร์ดติดตั้งมีลักษณะเฉพาะตัว ทำให้กลไกสแกนของหุ่นมีสูตรคำนวณขอบเขตด้านหน้าหุ่นดังนี้:  
พารามิเตอร์ของ LiDAR ถูกประกาศไว้ในฟังก์ชัน `__init__` ของโหนด `teleop_stm` :

1. **`self.stop_dist_lidar = 1.2` (ระยะหยุดเบรกฉุกเฉิน) \[จูนในไฟล์รอง `teleop_stm.py` เท่านั้น\]:**  
   ระยะห่างต่ำสุดในแนวเมตรที่ยิงไปชนวัตถุหน้าตรงแล้วจะหยุดฉุกเฉิน  
2. **`self.safety_angle_rad = 0.785` (มุมจำกัดขอบสแกนหน้าตรง) \[จูนในไฟล์รอง `teleop_stm.py` เท่านั้น\]:**  
   ค่ามุมเรเดียน (+/- 45 องศา) รอบจุดศูนย์กลางหน้าหุ่นยนต์  
3. **`len(danger_points) >= 10` (ตัวกรอง Noise สัญญาณหลอก) \[จูนในไฟล์รอง `teleop_stm.py` เท่านั้น\]:**  
   LiDAR ต้องตรวจสะท้อนเจอวัตถุหน้าตรงพร้อมกันมากกว่า `10` จุดขึ้นไปในหนึ่งรอบสแกน ถึงจะยืนยันว่าเจออุปสรรคจริง ป้องกันปัญหารถเบรกหลอกเนื่องจากฝุ่น ควัน หรือมีใบหญ้าชูกลางพัดปลิวเข้ามาชนมุมกล้องชั่วขณะ  
   * ⚠️ **หมายเหตุผู้พัฒนา:** ในโค้ด `teleop_stm.py` บรรทัดที่ 769 มีคอมเมนต์ระบุว่าให้ปรับเป็น `25` เพื่อลดปัญหาเศษหญ้าปลิวผ่าน แต่ตัวเลขเรียกใช้จริงยังเป็น `10` หากหน้างานเกิดรถเบรกหลอกบ่อยจากเศษฝุ่นหรือหญ้า ให้ผู้พัฒนาระบบเข้าไปเปิดแก้ไฟล์รองบรรทัดที่ 770 เปลี่ยนเลข 10 เป็น 25 ได้เลย

## 4\. พารามิเตอร์สำคัญของระบบขับเคลื่อน  (Drive & Navigation Parameters)

เป็นพารามิเตอร์ควบคุมพฤติกรรมการเคลื่อนที่ ทิศทาง มิติกายภาพ และระบบฟิสิกส์จำลองของหุ่นยนต์ตัดหญ้า:

### 1\) พารามิเตอร์ควบคุมในซอฟต์แวร์นำทาง

* **`max_speed_ms` (ความเร็วขับเคลื่อนสูงสุดของล้อ) \[จูนผ่านไฟล์ Launch ได้\] ในไฟล์:**  
  * *คำอธิบาย:* พารามิเตอร์สำหรับจำกัดความเร็วสูงสุดในแนวเส้นตรง (m/s) ของหุ่นยนต์เพื่อความปลอดภัย  
  * *ค่าเริ่มต้นในโค้ดรอง:* `1.25`  
  * *การจูน:* **ให้แก้ไขที่ไฟล์ Launch (`hardware_bringup.launch.py`)** ในส่วนพารามิเตอร์ของ `teleop_stm_node` เพื่อความสะดวกรวดเร็วหน้างาน  
      
* **`BNO_OFFSET_DEG` (ค่าชดเชยทิศเหนือของเข็มทิศ IMU) \[จูนในไฟล์รอง `teleop_stm.py` เท่านั้น\] :**  
  * *คำอธิบาย:* ใช้ระบุองศาชดเชยเข็มทิศชี้ทิศเหนือของบอร์ด IMU BNO055 เพื่อปรับระดับทิศหน้าของหุ่นยนต์ตัดหญ้าในโปรแกรมให้หมุนหันตรงตามทิศเหนือจริงในสนาม GPS  
  * *ค่าเริ่มต้น:* `-190.0` (ที่บรรทัด 20 ของ `teleop_stm.py`)  
  * *การจูน:* เป็นตัวแปร Global Constant ในภาษา Python **ต้องเปิดเข้าไปแก้ไขบรรทัดที่ 20 ในไฟล์รอง `teleop_stm.py` โดยตรง**

### 2\) พารามิเตอร์ทางกายภาพหุ่นยนต์และระบบฟิสิกส์จำลอง  (URDF & Gazebo Physics)

พารามิเตอร์เหล่านี้ถูกกำหนดโครงสร้างอยู่ในไฟล์โมเดลหุ่นยนต์ **`mower_gazebo.xacro`** และเกี่ยวข้องกับการจำลองสภาพแวดล้อม:

* **`base_mass` (มวลรวมของตัวหุ่นยนต์) ในไฟล์:**  
  * *คำอธิบาย:* ค่าน้ำหนักจริงของตัวรถหุ่นยนต์ตัดหญ้าที่นำมาใช้คำนวณแรงเฉื่อยฟิสิกส์  
  * *ค่าปรับแต่ง:* `37.0` kg  
      
* **`track_offset_y` (ระยะเยื้องฐานล้อออกด้านข้าง) ในไฟล์:**  
  * *คำอธิบาย:* ระยะห่างจากจุดกึ่งกลาง of หุ่นยนต์ไปยังขอบล้อสายพานแต่ละข้าง  
  * *ค่าปรับแต่ง:* `0.25` m  
      
* **`wheel_separation` (ระยะห่างระหว่างล้อคู่ขับเคลื่อน) ในไฟล์:**  
  * *คำอธิบาย:* ระยะห่างรวมระหว่างกึ่งกลางของล้อซ้ายและขวา เพื่อใช้แปลงคำสั่งความเร็วเชิงเส้น/เชิงมุมเป็นความเร็วล้อ  
  * *ค่าปรับแต่ง:* `0.50` m  
      
* **`drive_wheel_radius` (รัศมีล้อหลักขับเคลื่อนหลัง) ในไฟล์:**  
  * *คำอธิบาย:* รัศมีของล้อหลักทำหน้าที่ขับเคลื่อนเพลาสายพาน  
  * *ค่าปรับแต่ง:* `0.08` m (เส้นผ่านศูนย์กลาง `0.16` m)  
      
* **`max_wheel_torque` (แรงบิดมอเตอร์สูงสุดล้อขับเคลื่อนจำลอง) ในไฟล์:**  
  * *คำอธิบาย:* การจำกัดแรงบิดล้อของมอเตอร์ในการลุยตมและไต่ทางชันจำลองใน Gazebo  
  * *ค่าปรับแต่ง:* `30.0` N.m  
      
* **`max_wheel_acceleration` (อัตราเร่งล้อสูงสุดจำลอง) ในไฟล์:**  
  * *คำอธิบาย:* อัตราเร่งของล้อสูงสุดในโปรแกรมฟิสิกส์เพื่อป้องกันไม่ให้รถจำลองกระชากล้อหมุนฟรี  
  * *ค่าปรับแต่ง:* `2.0` m/s²  
      
* **`<mu>` และ `<mu2>` (สัมประสิทธิ์แรงเสียดทานของหน้ายางล้อสายพาน) ในไฟล์:**  
  * *คำอธิบาย:* กำหนดความยึดเกาะถนนและหน้าดิน โดยจูนค่าขับเคลื่อนหลักล้อหลังไว้ที่ `1.5` ถึง `2.0` สำหรับแรงดึงปกติ และ `0.001` ถึง `0.01` สำหรับการอนุญาตให้ล้อเลี้ยวลื่นไถลด้านข้างแบบตีนตะขาบ (Skid Steer) ส่วนล้อหน้าอิสระ (Caster Wheels) ถูกกำหนดแรงเสียดทานไว้ที่ `0.0` ทั้งคู่เพื่อไม่ให้ต้านแรงบิดเลี้ยว  
      
* **จุดพิกัดติดตั้งตำแหน่งเลเซอร์วัดระยะ LiDAR (LiDAR Joint Origin Offset) ในไฟล์:**  
  * *คำอธิบาย:* พิกัดตำแหน่ง XYZ ของหัวยิงเลเซอร์เทียบกับแกนกึ่งกลางตัวรถ  
  * *ค่าปรับแต่ง:* `xyz="-0.25 0.0 0.545"`

## 5\. สถาปัตยกรรมโหนดและการไหลของข้อมูล  (ROS2 Node Relationship & Data Flow)

หุ่นยนต์ตัดหญ้าเครื่องนี้ ขับเคลื่อนผ่านโครงสร้างประมวลผลแบบกระจายตัวของ ROS2 จำนวน **8 โหนดหลัก** โดยแต่ละโหนดมีหน้าที่การรับส่งข้อมูลผ่าน Topics ต่างๆ แสดงความสัมพันธ์ดังตารางด้านล่างนี้:

### ความสัมพันธ์ของ Topics แต่ละโหนด

| ชื่อโหนด (Node Name) | หน้าที่หลักทางระบบ (Main Function) | หัวข้อที่สมัครรับข้อมูล (Subscribed Topics / Inputs) | ได้รับข้อมูลจากโหนดใด (Source Nodes) | หัวข้อที่ส่งออกข้อมูล (Published Topics / Outputs) | ส่งข้อมูลต่อไปให้โหนดใด (Destination Nodes) |
| :---- | :---- | :---- | :---- | :---- | :---- |
| **`vision_node`** | ใช้กล้อง D435i และ YOLOv11 ตรวจสอบ คน/หมา/แมว และทำแนวตรวจจับความปลอดภัย | `/camera/camera/depth/image_rect_raw` \`/camera/camera/color/image\_raw\` | RealSense Node | `/cmd_emergency` \`/camera/yolo/debug\_image\` \`/camera/yolo/performance\` | `teleop_stm` \`mow\_zigzag\` \`robot\_dashboard\` |
| **`teleop_stm`** | ตัวกลางสื่อสารแบบ Serial ต่อบอร์ด STM32 รับ ticks ล้อ/ส่งออก IMU, ควบคุมความปลอดภัยชั้นล่าง | `/cmd_vel` \`/scan\` \`/cmd\_emergency\` \`/emergency\_stop\` \`/imu/set\_north\` \`ultrasonic\_raw\` | `twist_mux` \`rplidar\_node\` \`vision\_node\` \`geofence\_and\_planner\` User Manual Arduino Serial | `/odom_raw` \`/imu/data\` \`/lidar\_safety\_status\` \`lidar\_safety\_marker\` | `ekf_localization` \`robot\_dashboard\` Rviz Visualization |
| **`ntrip_client`** | รับรหัสและค่าพิกัดแก้ผ่านเครือข่ายอินเทอร์เน็ตสถานีฐาน (CORS) ฉีดลงบอร์ด GPS | `/nmea_sentence` | ตัวเอง (GGA loop) | `/nmea_sentence` | `nmea_gps_node` (และยิง RTCM เข้าพอร์ตบอร์ด GPS จริง) |
| **`ultrasonic_converter`** | แปลงระยะห่างเซ็นเซอร์อัลตร้าโซนิก 3 ทิศทาง เป็นกลุ่มพิกัดจุด 3D Arc และกรองจุดบอด | `ultrasonic/left` \`ultrasonic/center\` \`ultrasonic/right\` | `arduino_reader` | `ultrasonic_pointcloud` | Nav2 local/global costmaps |
| **`auto_datum_node`** | ตั้งพิกัดจุดเริ่มต้น 0,0 ของแผนที่อัตโนมัติ โดยอิงจากหัวมุมแรกในพิกัดรั้วสนาม | *(ไม่มี \- อ่านพิกัดตรงจากไฟล์ `lawn_geofence.yaml`)* | \- | เรียกใช้งาน Service `/datum` | `navsat_transform_node` (ล็อกพิกัด map frame) |
| **`geofence_and_planner`** | ตรวจสอบขอบเขตหุ่นตกขอบรั้วแดงผ่าน Shapely คอยคำนวณเส้นทางเดินซิกแซกแบบกั้นพื้นที่ | `/fix` \`/cmd\_vel\_nav\_smoothed\` \`/cmd\_vel\_teleop\` \`TF (/map \-\> /base\_link)\` | `nmea_gps_node` \`velocity\_smoother\` Manual joystick EKF transform | `/emergency_stop` \`/cmd\_vel\_filtered\` \`/mowing\_path\` \`/geofence\_viz\` \`/mowing\_markers\` | `teleop_stm` \`mow\_zigzag\` \`twist\_mux\` Rviz Visualization |
| **`mow_zigzag`** | ล็อคหั่นแนวเส้นทางเดินเป็นเส้นตรง (Chunks) คอยติดตามงานและส่งต่อให้ Nav2 พร้อมเซฟรายงาน HTML | `/mowing_path` \`/fix\` \`/battery\_status\` \`/emergency\_stop\` \`/cmd\_emergency\` \`TF (/map \-\> /base\_link)\` | `geofence_and_planner` \`nmea\_gps\_node\` \`teleop\_stm\` (บอร์ดวัดไฟ) EKF transform | เรียกใช้งาน Action Server `follow_path` \*(บันทึกรายงานไฟล์ลง \`\~/mower\_reports/\`)\* | `nav2_controller` (Action client) Local File Storage |
| **`robot_dashboard`** | เฝ้าระวัง แสดงผลหน้าจอด้านสถานะอุปกรณ์ ความเร็ว แบตเตอรี่ เปอร์เซ็นต์ RTK แบบ Real-time | `/fix`, `/imu/data` \`/odom\_raw\` \`/scan\`, \`/battery\_status\` \`/cmd\_emergency\` \`/lidar\_safety\_status\` \`/camera/yolo/performance\` | `nmea_gps_node` \`teleop\_stm\` \`rplidar\_node\` \`vision\_node\` | *(ไม่มี \- แสดงผลข้อมูลออกหน้าจอ Terminal โดยตรง)* | ผู้พัฒนา / ผู้ควบคุมหน้างาน |

---

## 6\. การจูนพารามิเตอร์ระบบกล้อง AI  (AI Vision Parameter Tuning Guide)

การตรวจจับคน สิ่งมีชีวิต และขอบเขตความลึกเพื่อสั่งหยุดหุ่นยนต์ ใช้ YOLOv11 และ Depth Map ของกล้อง RealSense D435i ประมวลผลในโหนด [**vision\_node.py**](file:///home/nhio/ros2_ws/src/robot_bridge/robot_bridge/vision_node.py) โดยสามารถจูนค่าเพื่อปรับประสิทธิภาพการตรวจจับและความปลอดภัยได้ดังนี้:

### 1\) พารามิเตอร์หลักทางระบบ (ROS2 Launch Parameters)

พารามิเตอร์กลุ่มนี้มีประกาศใช้งานอยู่ทั้งในไฟล์หลัก Launch และโค้ดแกนหลัก Python:

* **จุดที่ต้องแก้ไข:** **\[จูนผ่านไฟล์ Launch ได้เลย\]** ให้ทำการจูนที่ไฟล์เปิดระบบหลัก [**hardware\_bringup.launch.py**](file:///home/nhio/ros2_ws/src/robot_bridge/launch/hardware_bringup.launch.py) (บรรทัด 18-22) เพียงจุดเดียวเท่านั้น ระบบจะดึงค่านี้ไปเขียนทับตัวแปรในโค้ด Python ให้โดยอัตโนมัติ  
* **`model_path` (ค่าเริ่มต้นในโค้ด: `'yolo11n.pt'`) ในไฟล์** **:**  
  * *คำอธิบาย:* ชื่อไฟล์น้ำหนักโมเดล YOLO ที่ใช้สแกนหาวัตถุ  
  * *การจูน:* สามารถเปลี่ยนไปใช้โมเดลที่แม่นยำขึ้น เช่น `'yolo11s.pt'` หรือไฟล์โมเดลที่ผ่านการเทรนเองได้  
* **`stop_distance` (ค่าเริ่มต้นในโค้ด: `4.0` เมตร) ในไฟล์** **:**  
  * *คำอธิบาย:* ระยะปลอดภัยของ AI ตรวจจับคน/หมา/แมว หากพบใกล้กว่าค่านี้จะสั่งหยุดเบรกฉุกเฉิน  
  * *การจูน:* ลดค่าลงได้หากต้องการให้หุ่นยนต์วิ่งเข้าเบียดขวางเป้าหมายได้ชิดขึ้น (เช่น `2.0` \- `3.0` เมตร)  
* **`fence_distance` (ค่าเริ่มต้นในโค้ด: `1.5` เมตร) ในไฟล์** **:**  
  * *คำอธิบาย:* ระยะตรวจจับวัตถุแปลกปลอมแบบรวมก้อนความลึก (Depth Fence) ซึ่งจะจับวัตถุทุกชนิดที่นูนขึ้นมาจากพื้นดิน  
  * *การจูน:* ปรับตามสภาพพื้นที่เพื่อป้องกันล้อหน้าเบียดชนขอบปูน กระถาง หรือดินสไลด์

---

### 2\) พารามิเตอร์ควบคุมอัลกอริทึมในโค้ด (Internal Algorithm Tuning)

สำหรับพารามิเตอร์เหล่านี้ไม่มีการเปิดระบบพารามิเตอร์ลิงก์ไว้กับ Launch File:

* **จุดที่ต้องแก้ไข:** **\[จูนในไฟล์รอง (vision\_node.py) เท่านั้น\]** ผู้พัฒนาต้องเปิดไฟล์โค้ดหลัก [**vision\_node.py**](file:///home/nhio/ros2_ws/src/robot_bridge/robot_bridge/vision_node.py) เพื่อเข้าไปแก้ไขตัวเลขบรรทัดโค้ดโดยตรง:  
* **ค่าความมั่นใจในการตรวจจับของ YOLO (`conf=0.4`):**  
  * *คำอธิบาย:* เกณฑ์คะแนนขั้นต่ำที่ยอมรับว่าวัตถุที่เห็นคือเป้าหมายคน/สัตว์จริง  
  * *การจูน:* เพิ่มขึ้นเป็น `0.5` หรือ `0.6` หากต้องการแก้ปัญหา AI ตรวจจับใบไม้หรือเสาเป็นคน (ลดปัญหาเบรกฉุกเฉินหลอก)  
* **ขนาดภาพอินพุตกล้องของโมเดล (`imgsz=320`):**  
  * *คำอธิบาย:* ขนาดพิกเซลที่บีบอัดก่อนส่งป้อนให้ YOLO AI สแกน  
  * *การจูน:* ตัวเลข `320` ถูกตั้งไว้เพื่อให้เรียกใช้เร็วจานลื่นบน Raspberry Pi 5 หากนำไปเรียกใช้บนคอมพิวเตอร์การ์ดจอสูง สามารถปรับเป็น `640` เพื่อให้ตรวจจับเป้าหมายขนาดจิ๋วที่ระยะไกลได้แม่นยำขึ้นมาก  
* **จำนวนเฟรมยืนยันวัตถุ AI (`CONFIRM_FRAMES_AI = 5`):**  
  * *คำอธิบาย:* จำนวนเฟรมภาพติดต่อกันที่ต้องเจอ คน/หมา/แมว ก่อนสั่งส่งเบรกจริง (5 เฟรม \= \~0.33 วินาที ที่ความเร็ว 15 FPS)  
  * *การจูน:* ทำหน้าที่กรองแสงสะท้อนหรือภาพกะพริบ ปรับลดลงเหลือ `2` \- `3` หากต้องการเบรกเร็วดั่งใจคิด หรือเพิ่มเป็น `8` \- `10` เพื่อความนุ่มนวลในการเคลื่อนที่  
* **จำนวนเฟรมยืนยันกำแพงความลึก (`CONFIRM_FRAMES_FENCE = 5`):**  
  * *คำอธิบาย:* จำนวนเฟรมภาพติดต่อกันที่สัญญาณ Depth รุกล้ำขอบเขตเข้ามา  
  * *การจูน:* ช่วยกรองเม็ดฝุ่นหรือแสงสะท้อนแดดจัดบนหญ้าเปียกไม่ให้ขวางรถตัดหญ้า  
* **เกณฑ์ความกว้างจำนวนพิกเซลสั่งชนกล้อง (`len(close_points) > 1500`):**  
  * *คำอธิบาย:* จำนวนจุดพิกเซลความลึกที่พบใกล้เกินระยะ `fence_distance` ภายในกรอบ ROI สแกน  
  * *การจูน:* เพิ่มขึ้นเป็น `2500` \- `3000` เพื่อข้ามการเบรกฉุกเฉินเมื่อเจอต้นหญ้าเดี่ยวๆ ชูช่อสูง หรือลดลงเหลือ `800` เพื่อความละเอียดปลอดภัยสูงสุด  
* **ระยะหน่วงหยุดของเบรกขั้นต่ำ (`MIN_STOP_DURATION = 0.5` วินาที):**  
  * *คำอธิบาย:* เวลาดึงเบรกค้างขั้นต่ำหลังความปลอดภัยถูกสั่งให้หยุด (ระบบป้องกันเบรกสั่นกระตุก)  
  * *การจูน:* เพิ่มเป็น `1.0` วินาทีเพื่อปกป้องชุดมอเตอร์เกียร์ล้อจากความเสียหายของการเบรกถี่  
* **รายการพืชที่กดยกเว้นการชน (Plant Bypass List) \[บรรทัด 133-134\]:**  
  * *คำอธิบาย:* ระบบระบุให้คลาส `'potted plant'` (ไม้กระถาง/พืช) ถือเป็นข้อยกเว้น โดยระบบจะหักลบพื้นที่ Bounding Box ของต้นไม้ออกจากการคำนวณ Depth Fence ป้องกันไม่ให้รถตัดหญ้าเบรกกระทันหันเมื่อวิ่งเฉียดใบไม้  
  * *การจูน:* สามารถเพิ่มคลาสพืชในโมเดลคัสตอมอื่นๆ หรือคลาสธรรมชาติเข้าไปในโค้ดเพิ่มเพื่ออำนวยความสะดวกในการวิ่งผ่านธรรมชาติได้

---

### 3\) ระบบกำแพงความลึกหน้ารถตรง  (Depth Safety Fence \- ROI & Pixel Tuning)

แนวกั้นความปลอดภัยกล้องความลึก **\[Depth Safety Fence\]** ในไฟล์ **`vision_node.py`** ทำงานโดยกวาดดูแนวความลึกหน้ารถตรงและสั่งหยุดทันทีหากมีวัตถุนูนใดๆ โผล่เข้ามาขวางทาง (เช่น หิน ก้อนดิน ถังน้ำ โครงเหล็ก) โดยระบบความปลอดภัยตัวนี้ใช้พิกัดกล้องควบคุมพื้นที่สแกนดังนี้:

| vision\_node.py : |
| :---- |
| `roi_x1, roi_x2 = int(w * 0.0), int(w * 1.0)  # แนวนอน (ซ้ายสุดไปขวาสุด) roi_y1, roi_y2 = int(h * 0.2), int(h * 0.65) # แนวตั้ง (บนลงล่าง)` |

* **จุดที่ต้องแก้ไข:** **\[จูนในไฟล์รอง (vision\_node.py) เท่านั้น\]** การทำงานของ Depth Fence จะจำกัดกรอบพื้นที่ในหน้าจอภาพเพื่อกรองสิ่งแวดล้อมดังนี้:  
  * **ขอบบน (`roi_y1 = int(h * 0.2)`):** บีบขอบบนลงมา 20% เพื่อตัดท้องฟ้า ทิวทัศน์ หรือต้นไม้ที่อยู่สูงพ้นตัวหุ่นยนต์ออกไป จะได้ไม่จับวัตถุด้านบนมาเบรก  
  * **ขอบล่าง (`roi_y2 = int(h * 0.65)`):** **(จุดวิเคราะห์สำคัญ)** บีบขอบล่างขึ้นไปสูงกว่าขอบจริง 35% เพื่อหลีกเลี่ยงไม่ให้กล้องเผลอก้มไปมองเห็น **"ฝากระโปรงรถตัวเอง หรือพื้นดินใต้ล้อตรงหน้าตรง"** ซึ่งหากไม่บีบขอบนี้ขึ้น รถตัดหญ้าจะอ่านเจอตัวรถตัวเองและสั่งล็อกเบรกถาวรทันที  
  * **การจูนหน้างาน:**  
    * หากรถเบรกหลอกเพราะสแกนเจอขอบฝาครอบบอดี้ของตัวเอง ➡️ ให้ลดค่า `0.65` เหลือ **`0.60`** หรือ **`0.58`** เพื่อยกกรอบล่างพ้นตัวรถขึ้นไป  
    * หากรถวิ่งชนกระถางต้นไม้หรือขอบปูนกั้นหญ้าที่สูงระดับต่ำเตี้ยดิน ➡️ ให้เพิ่มค่า `0.65` เป็น **`0.70`** เพื่อเปิดตามองมุมก้มกวาดพื้นให้ต่ำลงกว่าเดิม

---

## 

## 7\. เครื่องมือคำสั่งตรวจสอบข้อมูลและสืบค้น  (CLI Sniffing & Diagnosis)

ในการทดสอบระบบและเฝ้าระวังสัญญาณจริงบนตัวรถตัดหญ้า คุณสามารถเปิดใช้งานคำสั่งสากลของ ROS2 เพื่อ "ดักฟัง" หรือ "สแกนหาข้อบกพร่อง" ได้ทันทีผ่าน Terminal:

### 1\. การสืบหาและรายการหัวข้อส่งสัญญาณทั้งหมด (Topic Hunting)

เพื่อสแกนหาว่า ณ ปัจจุบัน มีช่องสัญญาณ Topic ตัวไหนกำลังพูดคุยกันอยู่ในหุ่นยนต์บ้าง:

`ros2 topic list`

### 2\. การดักฟังดูข้อมูลพารามิเตอร์แบบ Real-time (Sniffing Data)

หากผู้พัฒนาต้องการจับเข่าส่องตัวเลขข้อมูลสดๆ ที่ส่งออกมารอบต่อวินาที:

* **ดักฟังความเร็วที่ถูกสั่งให้หุ่นตัดหญ้าวิ่งอัตโนมัติ:**  
    
  `ros2 topic echo /cmd_vel_filtered`  
    
* **ดักฟังสถานะความปลอดภัยของแนวรั้ว Geofence (0 \= ปลอดภัย, 1 \= ทะลุรั้วให้สั่งเบรก):**  
    
  `ros2 topic echo /emergency_stop`  
    
* **ดักฟังข้อความสั่งหยุดรถฉุกเฉินจากกล้อง AI Vision / เลเซอร์ LiDAR:**  
    
  `ros2 topic echo /cmd_emergency`  
    
* **ดักฟังพิกัดดาวเทียมดิบ ละติจูด ลองจิจูด และชนิดสัญญาณดาวเทียม:**  
    
  `ros2 topic echo /fix`

### 3\. ตรวจสอบความถี่ความแรงของสัญญาณ (Frequency & Rate Check)

ใช้เพื่อเช็คว่าโหนดปลายทางเกิดอาการค้างหรือส่งข้อมูลขาดช่วงช้าเกินไปหรือไม่:

* **เช็คความถี่การทำงานของเลเซอร์สแกน LiDAR (ปกติควรส่งที่ความถี่ 7-10 Hz):**  
    
  `ros2 topic hz /scan`  
    
* **เช็คความเร็วการตอบกลับสัญญาณของ EKF Sensor Fusion (ปกติควรส่งที่ความถี่ 10-20 Hz):**  
    
  `ros2 topic hz /odometry/global`

### 

### 4\. ตรวจสอบเส้นทางสอดรับภายในโหนดปลายทาง (Node Inspection)

ต้องการส่องข้อมูลเชิงลึกของโหนดควบคุมหลัก `teleop_stm` ว่ามันรับข้อมูลจากโหนดไหนบ้างและส่งให้โหนดไหนอยู่:

`ros2 node info /teleop_stm`

### 5\. การเรียกใช้และดึงค่า Parameter นอกสถานที่

ต้องการสอบถามสมองหุ่นยนต์ว่า ขณะนี้เราเปิดใช้งานระบบข้ามความปลอดภัย (Bypass Mode) อยู่หรือไม่:

`ros2 param get /teleop_stm bypass_safety`

---

## 8\. การจูนระบบนำทางและควบคุมทิศทาง (Nav2 & FollowPath Parameter Tuning)

ในการเรียกใช้นำทางตัดหญ้าในสนามจริง ปัญหาท้าทายหลักทางวิศวกรรมของรถหุ่นยนต์ขับเคลื่อนแบบตีนตะขาบ/สายพานคือ **"แรงเสียดทานต้านการเลี้ยวที่หนืดมากของตีนตะขาบกับหน้าดิน (Track Friction)"** และ **"ความเฉื่อยสะสมขณะเบรกหรือเข้าโค้ง"**

เพื่อควบคุมการขับเคลื่อนให้มีความสม่ำเสมอ หน้ารถไม่ส่าย และเลี้ยวได้อย่างแม่นยำไม่ล้ำรั้วแปลงดิน วิศวกรสามารถเข้าไปจูนพารามิเตอร์การทำงานในระบบนำทาง Nav2 ได้ที่ไฟล์คอนฟิกหลักดังนี้:

* **พาธไฟล์สำหรับจูนค่า:** **`~/ros2_ws/src/robot_bridge/config/nav2_params.yaml`**

---

### 

### 1\) การสปินตัวหันหน้ารถก่อนเริ่มเคลื่อนที่ไปข้างหน้า (Rotation Shim Controller)

เนื่องจากตีนตะขาบเป็นระบบเลี้ยวที่ต้องการแรงบิดสูง หากหุ่นยนต์พยายามเลี้ยวเลาะโค้งไปพร้อมกับเดินหน้าทันที ล้อจะกินสไลด์ดินจนตีนตะขาบหลุด หรือหน้ารถจะเบียดชนขอบกำแพงก่อนเลี้ยวพ้น ปลั๊กอินควบคุมทิศทางจึงใช้ระบบหมุนคาลิเบรตทิศทางก่อนเดินหน้า:

* **พารามิเตอร์จูนค่า (ในไฟล์ `FollowPath`):**  
  * `angular_dist_threshold: 0.785` (หน่วยเรเดียน เทียบเท่ากับมุม **45 องศา**) **ในไฟล์**:  
    * *หลักการทำงาน:* หากหมุดพิกัด Waypoint นำทางถัดไป มีทิศทางที่เอียงเบี่ยงเบนต่างจากแนวหน้ารถปัจจุบันเกิน 45 องศา **ตัวหุ่นยนต์จะสั่งล็อกรอบล้อไม่ให้ขยับเดินหน้าตรงชั่วคราว แล้วทำสปินหมุนกลับหัวอยู่กับที่ (In-place Spin) จนกระทั่งทิศหน้ารถชี้ตรงหมุด 100% ก่อน จึงเริ่มปลดล็อกเร่งความเร็วเดินหน้าตามเส้นทาง** ป้องกันอาการเบียดเลี้ยววงกว้างชนรั้วได้ 100%  
  * `rotate_to_heading_angular_vel: 1.0` **ในไฟล์** (ความเร็วในการหมุนสปินตัว ปรับจูนไว้ที่ `1.0` rad/s เพื่อกาเรียกใช้ตีว่าบอร์ดขับมีกระแสไฟฟ้าส่งกำลังมากพอที่จะสับสลัดหน้าดินหนา)  
  * `max_angular_accel: 2.5` **ในไฟล์** (แรงเร่งเชิงมุมเพื่อให้รถหันสปินหัวเรือได้สว่างคมกระชับฉับไว)

---

### 2\) การจูนระยะเป้าล่อและความเร็วเข้าโค้ง (Regulated Pure Pursuit)

อัลกอริทึมแกนนำหลักในการเคลื่อนที่ตามเส้นทางคือ **Regulated Pure Pursuit (RPP)**:

* **พารามิเตอร์จูนค่า (ในไฟล์ `FollowPath`):**  
  * `desired_linear_vel: 0.4` **ในไฟล์** (จำกัดความเร็วแนวเส้นทางตรงสูงสุดไว้ที่ 0.4 m/s เพื่อความปลอดภัยและถนอมใบมีดตัดหญ้าให้สม่ำเสมอ)  
  * `min_lookahead_dist: 0.25` และ `max_lookahead_dist: 0.6` **ในไฟล์** (ความสั้น-ยาวของเสาสัญญาณ Carrot ที่ยื่นล่อหน้าหุ่นยนต์ หากจูนสั้นเกินไป รถจะเดินตัวส่ายเป็นเกลียวเลื้อยแบบงู หากจูนยาวเกินไป รถจะประมวลตัดโค้งปาดรั้วขอบทางเดิน)  
  * `min_rotational_vel: 0.6` **ในไฟล์** (ความเร็วเลี้ยวต่ำสุด ตั้งกั้นความฝืดสายพานไว้ที่ `0.6` เพื่อให้ตีนตะขาบขยับเลี้ยวโค้งได้นุ่มนวลโดยไม่มีอาการฝืนหนืดล็อกตัว)  
  * `use_regulated_linear_velocity_scaling: true` **ในไฟล์** (ระบบเฉลี่ยลดความเร็วทางตรงสัมพันธ์กับความชันโค้งโดยอัตโนมัติ ยิ่งโค้งหักศอกความเร็วยิ่งผ่อนเพื่อรักษาเสถียรภาพตัวถัง)

---

### 

### 

### 3\) การป้องกันหุ่นยนต์จอดค้างจากอาการล้อฟรีหนืดหญ้า (Stall Prevention)

บนสนามหญ้าชื้นหรือดินปนทราย รถตัดหญ้าอาจสะดุดเนินดินเตี้ยๆ หรือจมหล่มชั่วขณะจนระบบเข้าใจผิดว่าติดขัดถาวรแล้วส่งผลให้ยกเลิกภารกิจนำทาง ("Controller failed to make progress")

* **พารามิเตอร์จูนค่า (ในไฟล์ `progress_checker`):**  
  * `required_movement_radius: 0.01` **ในไฟล์** (ลดระยะกวาดคืบคลานขั้นต่ำเหลือเพียง 1 เซนติเมตร เพื่อป้องกันอาการจับ Abort ย่อย)  
  * `movement_time_allowance: 60.0` **ในไฟล์** (เพิ่มเวลาทดลองขยับหนีหล่มขึ้นเป็น **60.0 วินาที** เพื่อเปิดโอกาสให้ระบบฝังตัวสปินตัวหันจูนเข็มทิศพิกัดให้เสร็จสิ้นโดยไม่มีการแจ้งภารกิจแท้งกลางคัน)

---

### 4\) การเกลี่ยแรงเร่งเพื่อรักษาระบบพิกัดลอยตัว (Velocity Smoother Tuning)

กรองความเร่งต้านแรงกระชากแรงม้าของล้อมอเตอร์ตีนตะขาบขณะเริ่มเลี้ยวและหยุดจอด

* **พารามิเตอร์จูนค่า (ในไฟล์ `velocity_smoother`):**  
  * `max_accel: [0.5, 0.0, 2.5]` **ในไฟล์** (จำกัดแรงเร่งแนวตรงไม่ให้กระชากเกิน 0.5 m/s² เพื่อป้องกันอาการล้อตีนตะขาบฟรีหมุนลื่นไถลตอนสตาร์ท)  
  * `max_decel: [-1.0, 0.0, -2.5]` **ในไฟล์** (จำกัดแรงชะลอจอดไว้ที่ \-1.0 m/s² เพื่อให้จอดรถนิ่มสงบ ค่อยๆ หยอดความเร็ว ป้องกันแรงเฉื่อยรถกระตุกสะเทือนจนค่า EKF/IMU เกิดดริฟต์ลอยขึ้นมา)

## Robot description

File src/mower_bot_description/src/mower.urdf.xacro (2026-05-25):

<?xml version="1.0"?>
<robot name="tracked_mower" xmlns:xacro="http://ros.org/wiki/xacro">

  <xacro:property name="base_mass" value="13.14"/>
  <xacro:property name="base_x" value="0.50"/>
  <xacro:property name="base_y" value="0.24"/>
  <xacro:property name="base_z" value="0.14"/>

  <xacro:property name="track_mass" value="6.06"/>
  <xacro:property name="track_width" value="0.10"/>
  <xacro:property name="track_length" value="0.50"/> <xacro:property name="track_height" value="0.09"/>
  <xacro:property name="track_offset_y" value="0.20"/> <xacro:property name="drive_wheel_radius" value="0.095"/> <xacro:property name="drive_wheel_width" value="0.05"/>

  <link name="base_footprint"/>

  <joint name="base_joint" type="fixed">
    <parent link="base_footprint"/>
    <child link="base_link"/>
    <origin xyz="0 0 ${drive_wheel_radius}" rpy="0 0 0"/>
  </joint>

  <link name="base_link">
    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
    <inertial>
      <mass value="${base_mass}"/>
      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
    </inertial>
  </link>

  <xacro:macro name="visual_track" params="prefix reflect">
    <link name="${prefix}_track_mid_visual">
      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
      </link>

    <joint name="${prefix}_track_mid_joint" type="fixed">
      <parent link="base_link"/>
      <child link="${prefix}_track_mid_visual"/>
      <origin xyz="0 ${reflect * track_offset_y} 0" rpy="0 0 0"/>
    </joint>

    <link name="${prefix}_track_front_visual">
      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
    </link>

    <joint name="${prefix}_track_front_joint" type="fixed">
      <parent link="base_link"/>
      <child link="${prefix}_track_front_visual"/>
      <origin xyz="${(track_length - 0.18) / 2} ${reflect * track_offset_y} 0" rpy="1.5708 0 0"/>
    </joint>

    <link name="${prefix}_track_rear_visual">
      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
    </link>

    <joint name="${prefix}_track_rear_joint" type="fixed">
      <parent link="base_link"/>
      <child link="${prefix}_track_rear_visual"/>
      <origin xyz="-${(track_length - 0.18) / 2} ${reflect * track_offset_y} 0" rpy="1.5708 0 0"/>
    </joint>
  </xacro:macro>

  <xacro:visual_track prefix="left" reflect="1"/>
  <xacro:visual_track prefix="right" reflect="-1"/>


  <xacro:macro name="drive_wheel" params="prefix location reflect_x reflect_y">
    <link name="${prefix}_${location}_wheel">
      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
      <inertial>
        <mass value="2.0"/>
        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
      </inertial>
    </link>

    <joint name="${prefix}_${location}_wheel_joint" type="continuous">
      <parent link="base_link"/>
      <child link="${prefix}_${location}_wheel"/>
      <origin xyz="${reflect_x * 0.18} ${reflect_y * track_offset_y} 0" rpy="-1.5708 0 0"/> 
      <axis xyz="0 0 1"/>
    </joint>
  </xacro:macro>

  <xacro:drive_wheel prefix="front" location="left" reflect_x="1" reflect_y="1"/>
  <xacro:drive_wheel prefix="front" location="right" reflect_x="1" reflect_y="-1"/>
  <xacro:drive_wheel prefix="rear" location="left" reflect_x="-1" reflect_y="1"/>
  <xacro:drive_wheel prefix="rear" location="right" reflect_x="-1" reflect_y="-1"/>

  <xacro:macro name="flipper" params="prefix location reflect_x reflect_y">
    <link name="${prefix}_${location}_flipper">
      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
      <inertial>
        <mass value="0.75"/>
        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
      </inertial>
    </link>

    <joint name="${prefix}_${location}_flipper_joint" type="revolute">
      <parent link="base_link"/>
      <child link="${prefix}_${location}_flipper"/>
      <origin xyz="${reflect_x * 0.25} ${reflect_y * 0.27} 0" rpy="0 0 0"/>
      <axis xyz="0 1 0"/>
      <limit lower="-1.57" upper="1.57" effort="50" velocity="1.0"/>
    </joint>
  </xacro:macro>

  <xacro:flipper prefix="front" location="left" reflect_x="1" reflect_y="1"/>
  <xacro:flipper prefix="front" location="right" reflect_x="1" reflect_y="-1"/>
  <xacro:flipper prefix="rear" location="left" reflect_x="-1" reflect_y="1"/>
  <xacro:flipper prefix="rear" location="right" reflect_x="-1" reflect_y="-1"/>

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
  <link name="laser_frame">
    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
  </link>
  <joint name="laser_joint" type="fixed">
    <parent link="base_link"/>
    <child link="laser_frame"/>
    <origin xyz="0 0 0.15" rpy="0 0 0"/>
  </joint>

  <link name="imu_link"/>
  <joint name="imu_joint" type="fixed">
    <parent link="base_link"/>
    <child link="imu_link"/>
    <origin xyz="0 0 0" rpy="0 0 0"/>
  </joint>

  <link name="camera_link">
    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
    <inertial>
      <mass value="0.1"/>
      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
    </inertial>
  </link>
  
  <joint name="camera_joint" type="fixed">
    <parent link="base_link"/>
    <child link="camera_link"/>
    <origin xyz="0.15 0 0.2" rpy="0 0 0"/> 
  </joint>

  <link name="camera_depth_frame"/>
  <joint name="camera_depth_joint" type="fixed">
    <parent link="camera_link"/>
    <child link="camera_depth_frame"/>
    <origin xyz="0 0 0" rpy="0 0 0"/> 
  </joint>

  <link name="gps_link">
    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
    <inertial>
      <mass value="0.05"/>
      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
    </inertial>
  </link>

  <joint name="gps_joint" type="fixed">
    <parent link="base_link"/>
    <child link="gps_link"/>
    <origin xyz="-0.1 0 0.3" rpy="0 0 0"/> 
  </joint>
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

</robot>

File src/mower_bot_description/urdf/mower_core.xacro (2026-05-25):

<?xml version="1.0"?>
<robot xmlns:xacro="http://ros.org/wiki/xacro" >

    <xacro:property name="base_mass" value="13.14"/>
    <xacro:property name="base_x" value="0.76"/>
    <xacro:property name="base_y" value="0.60"/>
    <xacro:property name="base_z" value="0.14"/>

    <xacro:property name="track_offset_y" value="0.25"/>
    <xacro:property name="drive_wheel_radius" value="0.05"/> 
    <xacro:property name="drive_wheel_width" value="0.05"/>

    <link name="base_footprint"/>

    <joint name="base_joint" type="fixed">
        <parent link="base_footprint"/>
        <child link="base_link"/>
        <origin xyz="0 0 0" rpy="0 0 0"/>
    </joint>

    <link name="base_link">
        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
        <inertial>
            <origin xyz="0 0 0.1" rpy="0 0 0"/>
            <mass value="13.14"/>
            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
        </inertial>
    </link>

    <xacro:macro name="drive_wheel" params="prefix location reflect_x reflect_y offset_x">
        <link name="${prefix}_${location}_wheel">
            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
            <inertial>
                <mass value="2.0"/>
                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
            </inertial>
        </link>

        <joint name="${prefix}_${location}_wheel_joint" type="continuous">
            <parent link="base_link"/>
            <child link="${prefix}_${location}_wheel"/>
            <origin xyz="${offset_x} ${reflect_y * track_offset_y} -0.001" rpy="-1.5708 0 0"/>
            <axis xyz="0 0 1"/>
        </joint>
    </xacro:macro>

    <xacro:macro name="passive_wheel" params="prefix location reflect_y offset_x">
        <link name="${prefix}_${location}_wheel">
            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
            <inertial>
                <mass value="0.5"/>
                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
            </inertial>
        </link>

        <joint name="${prefix}_${location}_wheel_joint" type="continuous">
            <parent link="base_link"/>
            <child link="${prefix}_${location}_wheel"/>
            <origin xyz="${offset_x} ${reflect_y * track_offset_y} -0.001" rpy="-1.5708 0 0"/>
            <axis xyz="0 0 1"/>
        </joint>
    </xacro:macro>
    
    <xacro:passive_wheel prefix="front" location="left" reflect_y="1" offset_x="0.5"/>
    <xacro:passive_wheel prefix="mid" location="left" reflect_y="1" offset_x="0.0"/>
    <xacro:drive_wheel prefix="rear" location="left" reflect_x="-1" reflect_y="1" offset_x="-0.5"/>

    <xacro:passive_wheel prefix="front" location="right" reflect_y="-1" offset_x="0.5"/>
    <xacro:passive_wheel prefix="mid" location="right" reflect_y="-1" offset_x="0.0"/>
    <xacro:drive_wheel prefix="rear" location="right" reflect_x="-1" reflect_y="-1" offset_x="-0.5"/>

    <xacro:macro name="visual_track" params="prefix reflect filename">
        <link name="${prefix}_track_visual">
            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
            <inertial>
                <mass value="2.0"/>
                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
            </inertial>
        </link>

        <joint name="${prefix}_track_joint" type="fixed">
            <parent link="base_link"/>
            <child link="${prefix}_track_visual"/>
            <origin xyz="0 0.5 0" rpy="0 0 0"/>
        </joint>
    </xacro:macro>

    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

    <link name="lidar_link">
        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
        <inertial>
            <mass value="0.1"/>
            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
        </inertial>
    </link>

    <joint name="lidar_mount_joint" type="fixed">
        <parent link="base_link"/>
        <child link="lidar_link"/>
        <origin xyz="-0.25 0 0.545" rpy="0 0 0"/>
    </joint>

    <link name="laser_frame">
        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
    </link>

    <joint name="laser_joint" type="fixed">
        <parent link="lidar_link"/>
        <child link="laser_frame"/>
        <origin xyz="0 0 0.0" rpy="0 0 3.1415"/> </joint>

    <link name="imu_link"/>
    <joint name="imu_joint" type="fixed">
        <parent link="base_link"/>
        <child link="imu_link"/>
        <origin xyz="0 0 0" rpy="0 0 0"/>
    </joint>

    <link name="camera_link">
        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
        <inertial>
            <mass value="0.1"/>
            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
        </inertial>
    </link>
    
    <joint name="camera_joint" type="fixed">
        <parent link="base_link"/>
        <child link="camera_link"/>
        <origin xyz="-0.13 0 0.45" rpy="0 0 0"/> 
    </joint>

    <link name="camera_depth_frame"/>
    <joint name="camera_depth_joint" type="fixed">
        <parent link="camera_link"/>
        <child link="camera_depth_frame"/>
        <origin xyz="0 0 0" rpy="-1.5708 0 -1.5708"/> 
    </joint>

    <link name="gps_link">
        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
        <inertial>
            <mass value="0.05"/>
            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
        </inertial>
    </link>

    <joint name="gps_joint" type="fixed">
        <parent link="base_link"/>
        <child link="gps_link"/>
        <origin xyz="-0.12 0 0.38" rpy="0 0 0"/> 
    </joint>

    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
    <link name="sonar_center">
        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
    </link>
    <joint name="sonar_center_joint" type="fixed">
        <parent link="base_link"/>
        <child link="sonar_center"/>
        <origin xyz="0.1 0 0.35" rpy="0 0 0"/>
    </joint>

    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
    <link name="sonar_left">
        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
    </link>
    <joint name="sonar_left_joint" type="fixed">
        <parent link="base_link"/>
        <child link="sonar_left"/>
        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
        <origin xyz="0.1 0.2 0.35" rpy="0 0 0.7854"/>
    </joint>

    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
    <link name="sonar_right">
        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
    </link>
    <joint name="sonar_right_joint" type="fixed">
        <parent link="base_link"/>
        <child link="sonar_right"/>
        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
        <origin xyz="0.1 -0.2 0.35" rpy="0 0 -0.7854"/>
    </joint>

</robot>

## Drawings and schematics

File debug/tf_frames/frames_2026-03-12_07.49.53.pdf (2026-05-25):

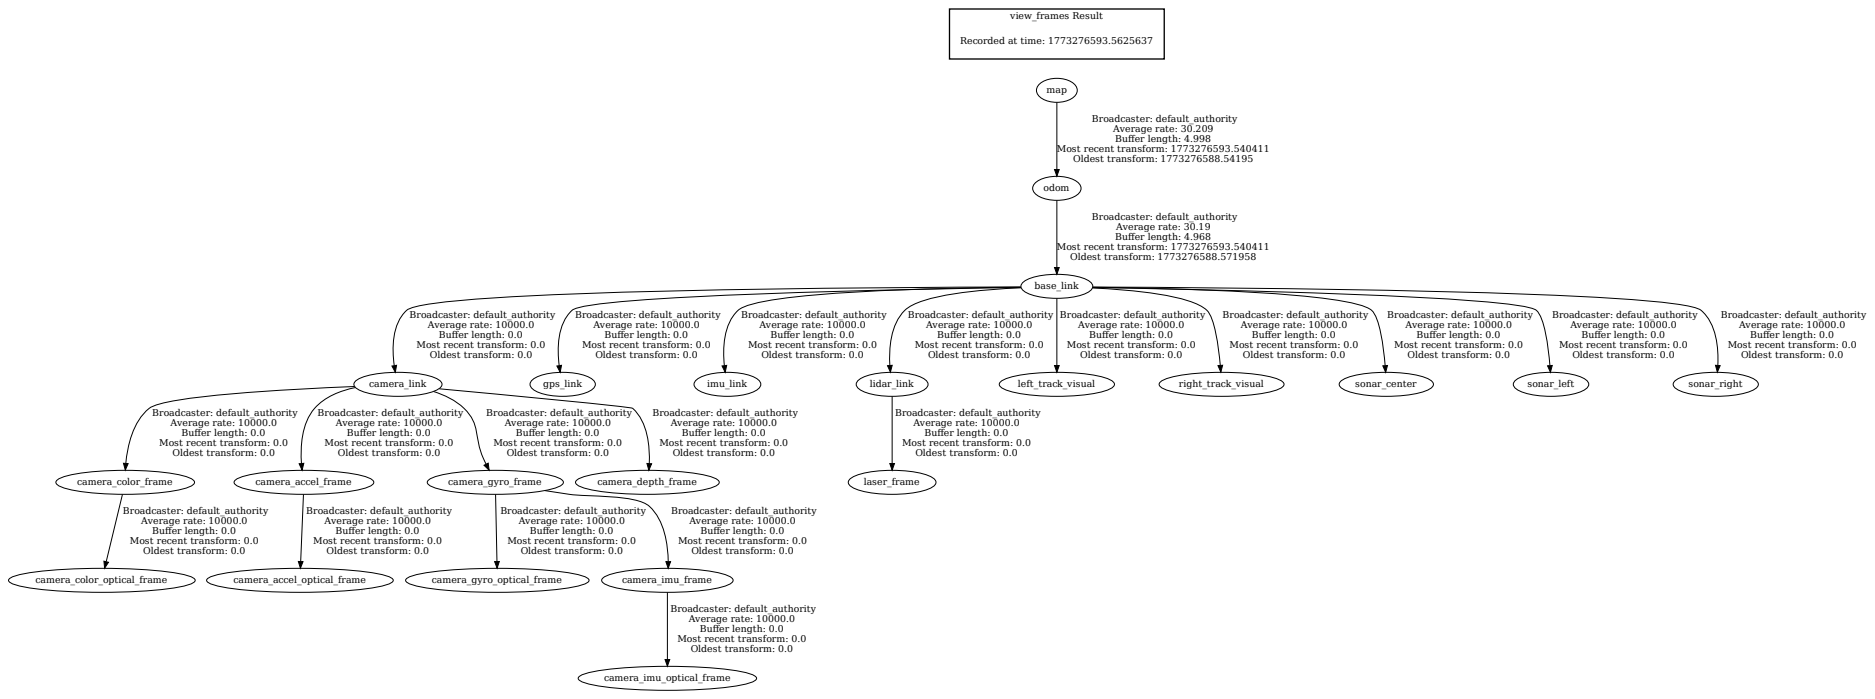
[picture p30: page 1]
view_frames Result; odom; base_link; Broadcaster: default_authority Average rate: 30.19 Buffer length: 4.968; camera_link; gps_link; imu_link; lidar_link; left_track_visual; right_track_visual; sonar_center; sonar_left; sonar_right; map; Broadcaster: default_authority Average rate: 30.209 Buffer length: 4.998; camera_color_frame; camera_accel_frame; camera_gyro_frame; camera_depth_frame; camera_color_optical_frame; camera_accel_optical_frame; camera_gyro_optical_frame; camera_imu_frame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

Recorded at time: 1773276593.5625637

Most recent transform: 1773276593.540411
Oldest transform: 1773276588.54195

Oldest transform: 1773276588.571958

Broadcaster: default_authority
Average rate: 10000.0
Buffer length: 0.0
Most recent transform: 0.0
Oldest transform: 0.0

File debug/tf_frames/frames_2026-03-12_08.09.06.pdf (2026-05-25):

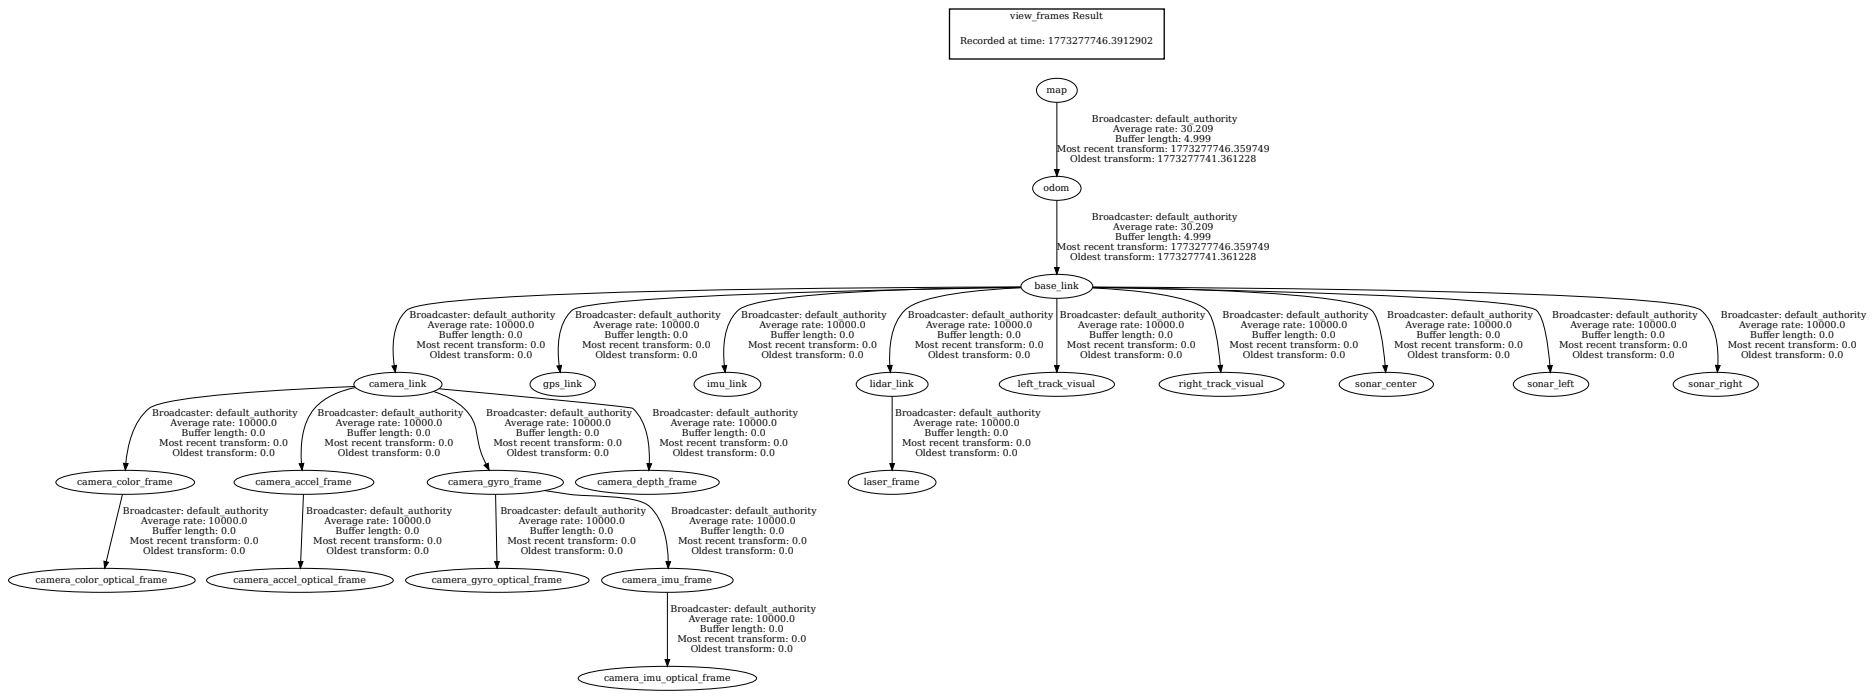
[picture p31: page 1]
view_frames Result; camera_link; camera_color_frame; camera_accel_frame; camera_gyro_frame; camera_depth_frame; camera_color_optical_frame; base_link; gps_link; imu_link; lidar_link; left_track_visual; right_track_visual; sonar_center; sonar_left; sonar_right; camera_accel_optical_frame; camera_gyro_optical_frame; camera_imu_frame; camera_imu_optical_frame; odom; Broadcaster: default_authority Average rate: 30.209 Buffer length: 4.999; laser_frame; map

Recorded at time: 1773277746.3912902

Most recent transform: 1773277746.359749
Oldest transform: 1773277741.361228

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

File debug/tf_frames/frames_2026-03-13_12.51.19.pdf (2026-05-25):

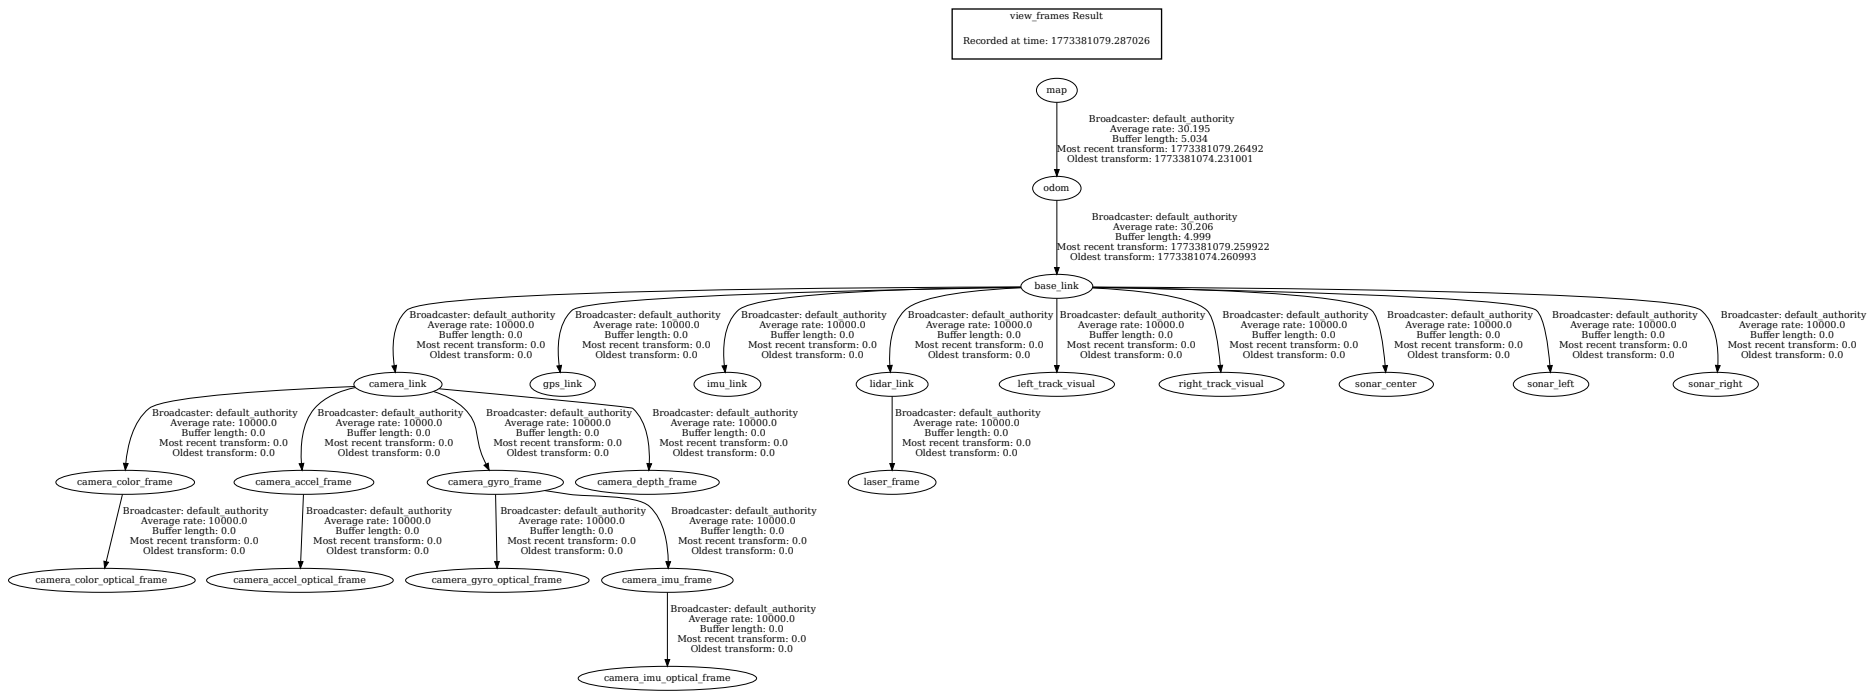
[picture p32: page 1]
view_frames Result; odom; base_link; Broadcaster: default_authority Average rate: 30.206 Buffer length: 4.999; camera_link; gps_link; imu_link; lidar_link; left_track_visual; right_track_visual; sonar_center; sonar_left; sonar_right; map; Broadcaster: default_authority Average rate: 30.195 Buffer length: 5.034; camera_color_frame; camera_accel_frame; camera_gyro_frame; camera_depth_frame; camera_color_optical_frame; camera_accel_optical_frame; camera_gyro_optical_frame; camera_imu_frame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

Recorded at time: 1773381079.287026

Most recent transform: 1773381079.26492
Oldest transform: 1773381074.231001

Most recent transform: 1773381079.259922
Oldest transform: 1773381074.260993

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

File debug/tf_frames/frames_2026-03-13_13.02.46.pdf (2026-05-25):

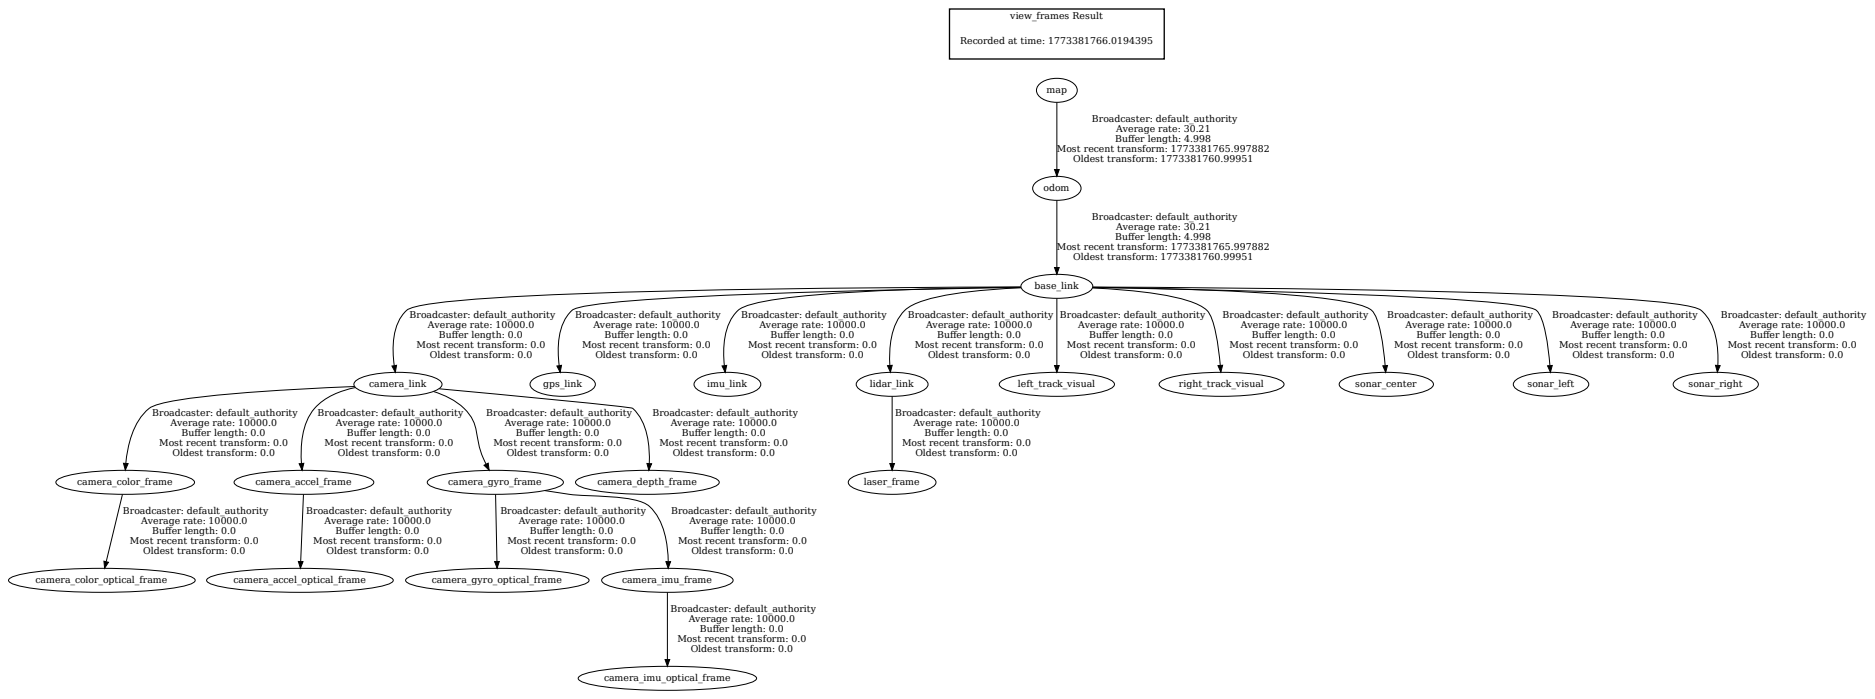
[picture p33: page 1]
view_frames Result; camera_link; camera_color_frame; camera_accel_frame; camera_gyro_frame; camera_depth_frame; camera_color_optical_frame; base_link; gps_link; imu_link; lidar_link; left_track_visual; right_track_visual; sonar_center; sonar_left; sonar_right; camera_accel_optical_frame; camera_gyro_optical_frame; camera_imu_frame; camera_imu_optical_frame; odom; Broadcaster: default_authority Average rate: 30.21 Buffer length: 4.998; laser_frame; map

Recorded at time: 1773381766.0194395

Most recent transform: 1773381765.997882
Oldest transform: 1773381760.99951

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

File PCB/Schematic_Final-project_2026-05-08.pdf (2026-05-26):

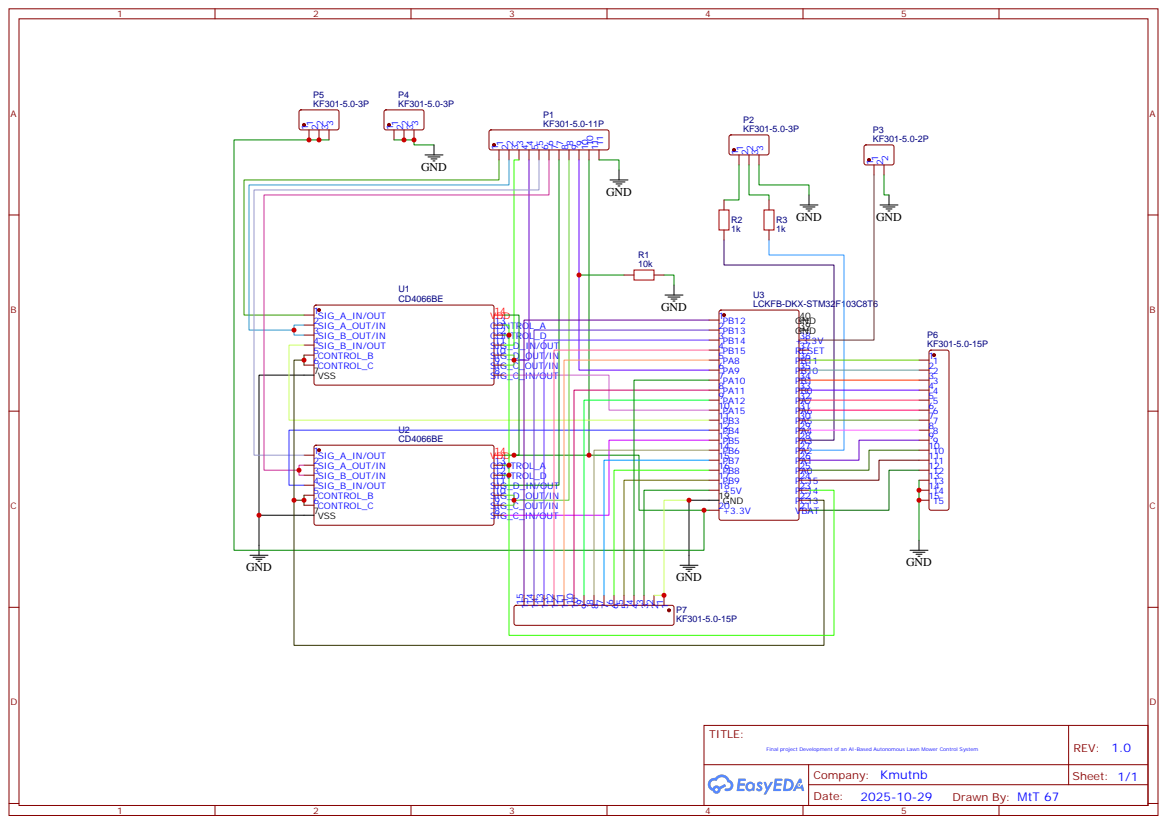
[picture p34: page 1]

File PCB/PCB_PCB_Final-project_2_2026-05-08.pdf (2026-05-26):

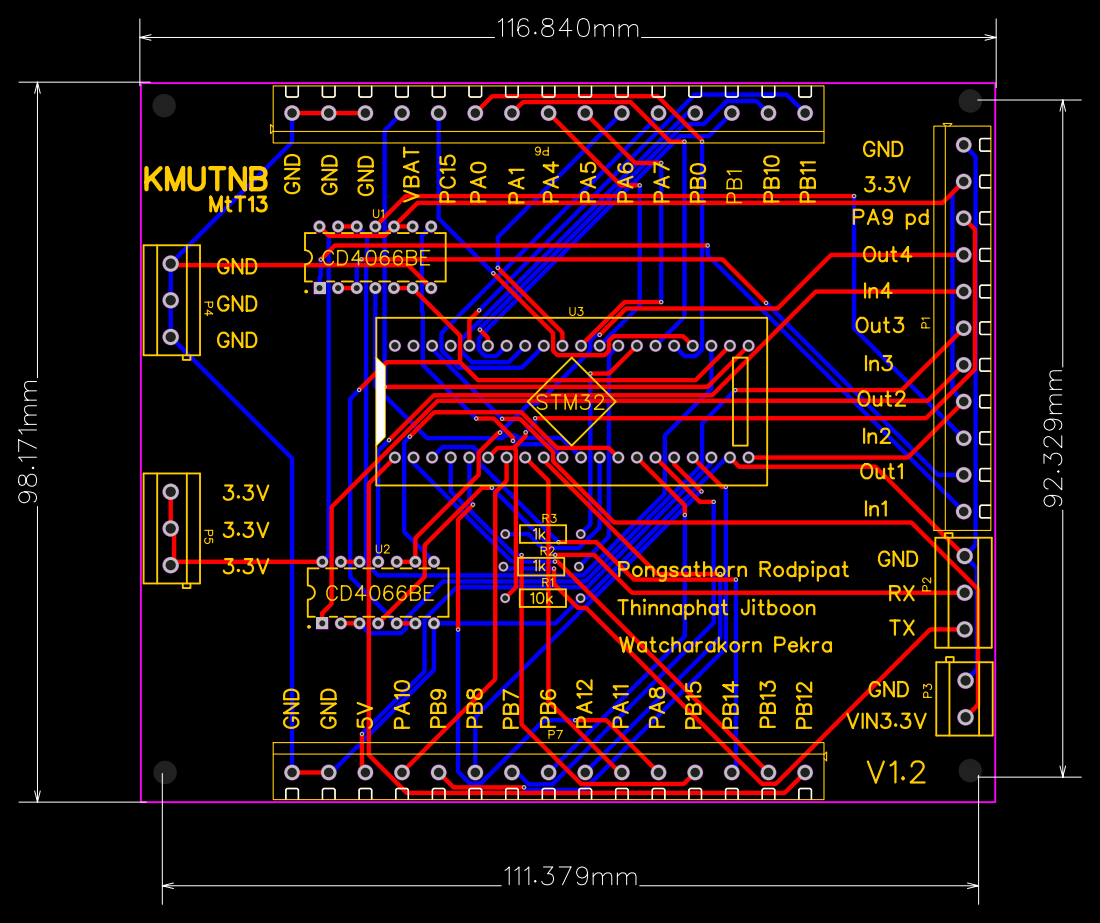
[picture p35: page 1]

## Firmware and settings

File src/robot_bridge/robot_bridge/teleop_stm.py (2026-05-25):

import rclpy
from rclpy.node import Node
from geometry_msgs.msg import Twist, PoseStamped, Point
from std_msgs.msg import Int8, Float64, String, Empty
from sensor_msgs.msg import Imu, LaserScan, NavSatFix
from visualization_msgs.msg import Marker
from nav_msgs.msg import Odometry
from diagnostic_msgs.msg import DiagnosticStatus, KeyValue, DiagnosticArray
import math
import serial
import serial.tools.list_ports
import threading
import time
import numpy as np
import json
import os

# 🟢 ตั้งค่า Offset สำหรับ BNO055 (องศา)
# ปรับเลขนี้เพื่อให้ทิศหน้าของหุ่นยนต์ตรงกับทิศเหนือจริง
BNO_OFFSET_DEG = -190.0

class TeleopSTMNode(Node):
    def __init__(self):
        super().__init__('teleop_stm')

        # พารามิเตอร์ของพอร์ต (เผื่อไว้ในกรณีที่หา Auto ไม่เจอ)
        self.declare_parameter('port', '/dev/ttyUSB0')
        self.declare_parameter('baudrate', 115200)
        self.declare_parameter('max_speed_ms', 1.25) # ⚠️ TODO: วัดจริงแล้วใส่ค่า max speed (m/s)
        self.declare_parameter('bypass_safety', True) # โหมดทดสอบ RTK-only (ข้ามระบบ Safety)

        self.baudrate = self.get_parameter('baudrate').value
        self.max_speed_ms = self.get_parameter('max_speed_ms').value
        self.bypass_safety = self.get_parameter('bypass_safety').value

        # ลบการล็อกพอร์ตตายตัว เปลี่ยนเป็น Dynamic Port Hunting
        self.port = None
        self.serial_conn = None
        self.is_connected = False

        # Publishers ของ Sensor กลับไปให้ ROS2
        self.pub_odom = self.create_publisher(Odometry, '/odom_raw', 10)
        self.pub_imu = self.create_publisher(Imu, '/imu/data', 10)

        # Publishers แยกล้อซ้าย-ขวา (สำหรับ Calibrate และเทียบกับ IMU)
        self.pub_enc_left_vel = self.create_publisher(Float64, '/encoder/left_velocity', 10)
        self.pub_enc_right_vel = self.create_publisher(Float64, '/encoder/right_velocity', 10)
        self.pub_enc_left_pos = self.create_publisher(Float64, '/encoder/left_position', 10)
        self.pub_enc_right_pos = self.create_publisher(Float64, '/encoder/right_position', 10)
        
        # --- Visual Debugging Topics ---
        self.pub_heading_visual = self.create_publisher(PoseStamped, '/robot/heading_visual', 10)
        self.pub_heading_marker = self.create_publisher(Marker, '/robot/heading_marker', 10)

        # Publisher สำหรับ Compass (True Heading 0-360 องศา จาก QMC5883L)
        self.heading_pub = self.create_publisher(Float64, '/compass/heading', 10)
        self.cal_pub = self.create_publisher(String, '/imu/calibration', 10)

        self.pub_serial_tx = self.create_publisher(String, '/serial/raw_tx', 10)
        self.pub_serial_rx = self.create_publisher(String, '/serial/raw_rx', 10)

        # 🚀 ย้ายมาไว้ตรงนี้เพื่อให้ระบบเริ่มส่ง Heartbeat ทันทีที่เปิดโปรแกรม
        self.timer = self.create_timer(0.1, self.heartbeat_loop)
        self.pub_serial_rx = self.create_publisher(String, '/serial/raw_rx', 10)

        # สร้าง Thread สำหรับจัดการการเชื่อมต่อ (Auto-Reconnect)
        self.monitor_thread = threading.Thread(target=self.connection_monitor_loop)
        self.monitor_thread.daemon = True
        self.monitor_thread.start()

        # --- ระบบจัดการ Offset ของ IMU ---
        self.offset_file = os.path.expanduser('~/ros2_ws/imu_offset.json')
        self.bno_offset = self.load_offset()
        self.latest_raw_yaw = 0.0 # เก็บค่าดิบไว้คำนวณ

        # สร้าง Thread สำหรับอ่านข้อมูลจาก STM32 ตลอดเวลา
        self.read_thread = threading.Thread(target=self.read_serial_data)
        self.read_thread.daemon = True
        self.read_thread.start()

        # ติดตามผลลัพธ์จาก EKF เพื่อเอามาโชว์ใน Marker
        self.sub_ekf = self.create_subscription(Odometry, '/odometry/global', self.ekf_callback, 10)
        
        self.sub_cmd_vel = self.create_subscription(Twist, 'cmd_vel', self.cmd_vel_callback, 10)
        self.sub_emergency = self.create_subscription(Int8, 'emergency_stop', self.emergency_callback, 10)
        
        # Topic สำหรับสั่งให้รถ "จำว่านี่คือทิศเหนือ"
        self.sub_set_north = self.create_subscription(Empty, '/imu/set_north', self.set_north_callback, 10)

        # รับข้อมูล U ดิบจาก Arduino Reader เพื่อส่งต่อให้ STM32
        self.sub_ultrasonic_raw = self.create_subscription(String, 'ultrasonic_raw', self.ultra_raw_callback, 10)
        
        # --- 🚨 AI Vision Emergency Stop Subscription ---
        self.vision_safe = True
        self.last_vision_msg_time = self.get_clock().now()
        self.sub_vision_emergency = self.create_subscription(String, '/cmd_emergency', self.vision_emergency_callback, 10)
        
        # --- 🛡️ LiDAR Visual Safety Marker ---
        self.marker_pub = self.create_publisher(Marker, 'lidar_safety_marker', 10)
        self.safety_angle_rad = 0.785 # +/- 45 องศา
        self.stop_dist_lidar = 1.2   # ระยะเบรก 1.2 ม.
        
        # --- 🛑 Nav2 Safety Sync & Verification ---
        from nav2_msgs.action import NavigateToPose
        from rclpy.action import ActionClient
        self.nav_client = ActionClient(self, NavigateToPose, 'navigate_to_pose')
        self.is_paused = False
        self.is_verifying = False
        self.verification_start_time = None
        self.pause_start_time = None
        self.VERIFY_DURATION = 2.0     # วินาทีที่ต้องปลอดภัยต่อเนื่องก่อนเดินต่อ
        self.MAX_PAUSE_DURATION = 60.0  # หยุดรอนานสุด 60 วินาทีก่อนยกเลิกงาน
    
        self.current_vL = 0.0  # m/s ล้อซ้าย
        self.current_vR = 0.0  # m/s ล้อขวา
        self.last_cmd_time = self.get_clock().now()

        # เก็บสถานะพิกัดสะสมของ Odom (X, Y, Theta)
        self.odom_x = 0.0
        self.odom_y = 0.0
        self.odom_th = 0.0
        self.latest_compass_yaw = 0.0  # เก็บค่า Yaw ล่าสุดจากเข็มทิศ (Radian)
        self.last_odom_time = self.get_clock().now()

        # Safety: ดักหมุนเกิน 1.5 รอบ (540°)
        self.rotation_accumulator = 0.0  # สะสมมุมหมุน (rad)
        self.ROTATION_LIMIT = 3.0 * 3.14159  # 1.5 รอบ = 540° = 3π rad
        self.rotation_safety_triggered = False
        self.pub_cmd_vel_override = self.create_publisher(Twist, 'cmd_vel', 10)

        # --- ระบบความปลอดภัยจาก LiDAR ---
        self.lidar_safe = True
        self.lidar_min_dist = 10.0 # เก็บระยะใกล้ที่สุดที่เจอ
        self.sub_scan = self.create_subscription(LaserScan, '/scan', self.lidar_callback, 10)
        
        # --- 🔋 Battery Monitoring Setup ---
        self.battery_pub = self.create_publisher(DiagnosticStatus, '/battery_status', 10)
        self.battery_volt = 0.0
        self.battery_curr = 0.0

        # --- 📢 Safety Status Publishers ---
        self.pub_lidar_status = self.create_publisher(String, '/lidar_safety_status', 10)
        self.pub_status = self.create_publisher(String, '/robot/status', 10)
        self.pub_battery = self.create_publisher(DiagnosticArray, '/robot/battery', 10)
        self.pub_volt = self.create_publisher(Float64, '/battery/voltage', 10)
        self.pub_curr = self.create_publisher(Float64, '/battery/current', 10)
        self.last_reported_status = ""

    def load_offset(self):
        """โหลดค่า Offset จากไฟล์ ถ้าไม่มีให้ใช้ค่า Default (160.0)"""
        if os.path.exists(self.offset_file):
            try:
                with open(self.offset_file, 'r') as f:
                    data = json.load(f)
                    self.get_logger().info(f"🟢 โหลด IMU Offset สำเร็จ: {data['offset']}°")
                    return data['offset']
            except:
                pass
        return 160.0 # Default เดิมของคุณ

    def save_offset(self, value):
        """บันทึกค่า Offset ลงไฟล์"""
        try:
            with open(self.offset_file, 'w') as f:
                json.dump({'offset': value}, f)
            self.get_logger().info(f"💾 บันทึก IMU Offset ใหม่เรียบร้อย: {value}°")
        except Exception as e:
            self.get_logger().error(f"🔴 บันทึก Offset พลาด: {e}")

    def vision_emergency_callback(self, msg):
        """รับสัญญาณหยุดฉุกเฉินจาก AI Vision"""
        self.last_vision_msg_time = self.get_clock().now()
        if msg.data == "E,1":
            if self.vision_safe:
                self.get_logger().error("🛑 [AI VISION] EMERGENCY STOP TRIGGERED!")
            self.vision_safe = False
        else:
            if not self.vision_safe:
                self.get_logger().info("🟢 [AI VISION] CLEAR - Resuming Operation")
            self.vision_safe = True

    def set_north_callback(self, msg):
        """คำสั่งตั้งค่าหน้าหุ่นให้เป็นทิศเหนือ (0 องศา)"""
        # สูตร: Offset ใหม่ = (360 - ค่าดิบปัจจุบัน) % 360
        new_offset = (360.0 - self.latest_raw_yaw) % 360.0
        self.bno_offset = new_offset
        self.save_offset(new_offset)
        self.get_logger().warn(f"🎯 ตั้งค่าทิศเหนือใหม่แล้ว! Offset ใหม่คือ: {new_offset:.2f}°")

        # รับข้อมูล U ดิบจาก Arduino Reader เพื่อส่งต่อให้ STM32
        self.sub_ultrasonic_raw = self.create_subscription(String, 'ultrasonic_raw', self.ultra_raw_callback, 10)

        # Timer ส่งคำสั่งซ้ำๆ (Heartbeat) ที่ 10Hz (0.1 วิ) เหมือนใน main_control.py
        self.timer = self.create_timer(0.1, self.heartbeat_loop)
    
        self.current_vL = 0.0  # m/s ล้อซ้าย
        self.current_vR = 0.0  # m/s ล้อขวา
        self.last_cmd_time = self.get_clock().now()

        # เก็บสถานะพิกัดสะสมของ Odom (X, Y, Theta)
        self.odom_x = 0.0
        self.odom_y = 0.0
        self.odom_th = 0.0
        self.latest_compass_yaw = 0.0  # เก็บค่า Yaw ล่าสุดจากเข็มทิศ (Radian)
        self.last_odom_time = self.get_clock().now()

        # Safety: ดักหมุนเกิน 1.5 รอบ (540°)
        self.rotation_accumulator = 0.0  # สะสมมุมหมุน (rad)
        self.ROTATION_LIMIT = 3.0 * 3.14159  # 1.5 รอบ = 540° = 3π rad
        self.rotation_safety_triggered = False
        self.pub_cmd_vel_override = self.create_publisher(Twist, 'cmd_vel', 10)
        
    def find_stm32_port(self):
        """ค้นหาพอร์ตอัตโนมัติ (หาเฉพาะ CH340 เท่านั้น)"""
        ports = serial.tools.list_ports.comports()
        
        # ลองหาตามเลขประจำตัวชิป (CH340) เท่านั้น
        for p in ports:
            hwid_str = str(p.hwid).upper()
            if (p.vid == 0x1A86 and p.pid == 0x7523) or ('1A86' in hwid_str and '7523' in hwid_str):
                self.get_logger().info(f"🟢 [Port Search] Found STM32 (CH340) at: {p.device}")
                return p.device
        
        # ❗ ไม่ Fallback ไปหยิบพอร์ตมั่วๆ เพื่อไม่ให้ไปแย่งพอร์ต GPS/Lidar
        return None

    def connection_monitor_loop(self):
        """วนลูปตรวจสอบและพยายามเชื่อมต่อพอร์ต USB อัตโนมัติ"""
        while rclpy.ok():
            if not self.is_connected or self.serial_conn is None or not self.serial_conn.is_open:
                # ทำการเคลียร์พอร์ตเก่าที่พัง
                if self.serial_conn:
                    try:
                        self.serial_conn.close()
                    except:
                        pass
                    self.serial_conn = None
                
                self.is_connected = False
                self.port = self.find_stm32_port()
                
                if self.port:
                    try:
                        self.serial_conn = serial.Serial(self.port, self.baudrate, timeout=0.05)
                        self.is_connected = True
                        self.get_logger().info(f"🟢 [STM32] ต่อพอร์ตสำเร็จที่: {self.port}")
                    except serial.SerialException as e:
                        self.get_logger().warn(f"🟡 [STM32] เจอพอร์ต {self.port} แต่เปิดไม่ได้: {e} (รอ 1 วิ)")
                else:
                    self.get_logger().warn(f"🔴 [STM32] สายหลุด! กำลังค้นหาบอร์ด (CH340)...")
                
                time.sleep(1.0) # รอ 1 วิก่อนลองเชื่อมใหม่
            else:
                time.sleep(2.0) # เช็คสุขภาพทุกๆ 2 วิ


    def cmd_vel_callback(self, msg):
        v_linear = msg.linear.x
        v_angular = msg.angular.z

        # Differential Drive: แปลง linear.x / angular.z → vL / vR (m/s)
        track_width = 0.50  # เมตร (แก้ไขจาก 0.70 ตามค่าจริง 50cm)
        vL = v_linear - (v_angular * track_width / 2.0)
        vR = v_linear + (v_angular * track_width / 2.0)

        # 🚀 Deadband Compensation: ชดเชยแรงเสียดทานของสายพานตอนหมุนตัว
        # ถ้ารถพยายามหมุนตัวอยู่กับที่ (v_linear ใกล้ 0) แต่แรงไม่พอ
        if abs(v_linear) < 0.05 and abs(v_angular) > 0.05:
            MIN_SPIN_SPEED = 0.15  # ความเร็วล้อขั้นต่ำที่ทำให้สายพานขยับได้บนหญ้า (m/s)
            if abs(vL) < MIN_SPIN_SPEED:
                vL = -MIN_SPIN_SPEED if vL < 0 else MIN_SPIN_SPEED
            if abs(vR) < MIN_SPIN_SPEED:
                vR = -MIN_SPIN_SPEED if vR < 0 else MIN_SPIN_SPEED

        # 🔍 DEBUG: เช็คว่าทำไมความเร็วถึงเหลือ 0.06
        self.get_logger().info(f"DEBUG: Recv v_ang={v_angular:.2f}, vL_raw={vL:.3f}, vR_raw={vR:.3f}")

        # ✅ อนุญาตให้ความเร็วล้อตอนเลี้ยวสูงกว่า max_speed_ms ได้ (สูงสุดที่ 1.2 m/s เพื่อความแรง)
        # เพื่อรองรับการหมุนตัวที่ 2.5 Rad/s
        abs_max = 0.4
        self.current_vL = max(-abs_max, min(abs_max, vL))
        self.current_vR = max(-abs_max, min(abs_max, vR))
        self.last_cmd_time = self.get_clock().now()

    def ultra_raw_callback(self, msg):
        # ส่งข้อความ U,x,y,z\n ตรงๆ ไปยัง STM32 เลย
        self.send_serial(msg.data)

    def emergency_callback(self, msg):
        state = msg.data # 0 = Normal, 1 = Emergency
        if not hasattr(self, 'last_emergency_state'):
            self.last_emergency_state = -1
            
        if state in [0, 1] and state != self.last_emergency_state:
            self.last_emergency_state = state
            # STM32 ต้องการ Checksum: state + 69
            chk = state + 69  
            cmd_str = f"E,{state},{chk}\n"
            self.send_serial(cmd_str)
            self.get_logger().warn(f"Emergency command sent: {state}")
            
            if state == 1:  # Emergency Stop
                # หยุดรถทันที + รีเซ็ต Safety
                self.current_vL = 0.0
                self.current_vR = 0.0
                self.rotation_accumulator = 0.0
                self.rotation_safety_triggered = False
                # ส่ง cmd_vel = 0 ให้ Nav2 รู้ว่าต้องหยุด
                stop_msg = Twist()
                self.pub_cmd_vel_override.publish(stop_msg)
                self.get_logger().warn('🛑 Emergency: หยุดรถ + ยกเลิกคำสั่ง Nav2')


    def heartbeat_loop(self):
        # ลด Safety Timeout ลงเหลือ 0.3 วินาที เพื่อไม่ให้หุ่นวิ่งไหลเวลาคอมมานด์หยุดครับ
        now = self.get_clock().now()
        if (now - self.last_cmd_time).nanoseconds > 3e8: # 0.3 seconds (300ms)
            self.current_vL = 0.0
            self.current_vR = 0.0

        # --- 🛡️ AI Vision Heartbeat Safety ---
        status = "OK"
        if not self.bypass_safety:
            if (now - self.last_vision_msg_time).nanoseconds > 2e9: # 2.0 seconds
                if self.vision_safe:
                    self.get_logger().error("⚠️ [AI VISION] Timeout! AI might have crashed. Stopping for safety.")
                    self.vision_safe = False
                status = "VISION_TIMEOUT"
        else:
            self.vision_safe = True  # bypass mode → ไม่สนใจ vision

        # --- 🔍 Determine Overall Status ---
        if not self.vision_safe: status = "VISION_TIMEOUT"
        elif not self.lidar_safe: status = "LIDAR_OBSTACLE"
        elif self.is_paused: status = "WAITING_VERIFY"
        elif (now - self.last_cmd_time).nanoseconds > 5e8: # 0.5s Timeout for Nav2
            status = "WAITING_NAV2"
        
        if hasattr(self, 'last_emergency_state') and self.last_emergency_state == 1:
            status = "EMERGENCY_STOP"

        # Publish Status (Only when changed to avoid spam)
        if status != self.last_reported_status:
            msg = String()
            msg.data = status
            self.pub_status.publish(msg)
            # เปลี่ยนเป็น warn เพื่อให้เป็นสีเหลือง สังเกตง่าย
            self.get_logger().warn(f"🔄 STATUS CHANGED: {status}")
            self.last_reported_status = status

        # เก็บสถานะปัจจุบันไว้ส่งไปพร้อม TX
        self.current_status_str = status

        # ส่ง Marker ไปโชว์ใน RViz
        self.publish_safety_marker()

        # ยิงคำสั่งปัจจุปันส่งไปหา STM32 รัวๆ (Continuous Heartbeat)
        self.send_control_cmd(self.current_vL, self.current_vR)

    def send_control_cmd(self, vL, vR):
        now = self.get_clock().now()
        if self.bypass_safety:
            is_safe = True
        else:
            is_safe = self.lidar_safe and self.vision_safe

        # --- 🛡️ ตรรกะ Pause & Verify ---
        if not is_safe:
            # ตรวจเจออุปสรรค -> สั่งหยุดทันที
            vL, vR = 0.0, 0.0
            if not self.is_paused:
                self.get_logger().warn("🚨 OBSTACLE DETECTED: Pausing and waiting for clear path...")
                self.is_paused = True
                self.pause_start_time = now
            self.is_verifying = False
            
            # เช็คว่ารอจนหมดความอดทนหรือยัง (60 วินาที)
            if self.pause_start_time and (now - self.pause_start_time).nanoseconds > (self.MAX_PAUSE_DURATION * 1e9):
                self.cancel_nav2_goal()
                self.pause_start_time = None 
        
        elif self.is_paused:
            # อุปสรรคหายไปแล้ว -> เริ่มขั้นตอน Verify
            vL, vR = 0.0, 0.0
            if not self.is_verifying:
                self.get_logger().info(f"🔍 Path Cleared: Verifying for {self.VERIFY_DURATION}s...")
                self.is_verifying = True
                self.verification_start_time = now
            
            # ตรวจสอบว่าปลอดภัยต่อเนื่องจนครบเวลาหรือยัง
            elapsed_verify = (now - self.verification_start_time).nanoseconds / 1e9
            if elapsed_verify >= self.VERIFY_DURATION:
                self.get_logger().info("🟢 Verification Complete: Resuming path following.")
                self.is_paused = False
                self.is_verifying = False

        vL_rounded = round(vL, 2)
        vR_rounded = round(vR, 2)
        vL_int = int(round(vL_rounded * 100))
        vR_int = int(round(vR_rounded * 100))
        
        chk = vL_int + vR_int
        cmd_str = f"C,{vL_rounded:.2f},{vR_rounded:.2f},{chk}\n"
        self.send_serial(cmd_str)

    def cancel_nav2_goal(self):
        """ยกเลิกงาน Nav2 เมื่อหยุดรอนานเกินไป"""
        self.get_logger().error("🛑 Obstacle persisted too long. Resetting pause state.")
        self.is_paused = False
        self.is_verifying = False
        self.pause_start_time = None

    def send_serial(self, data: str):
        # เพิ่มสถานะเข้าไปใน Log เพื่อให้เห็นชัดๆ ทุกบรรทัด
        status_tag = getattr(self, 'current_status_str', 'UNKNOWN')
        if status_tag == "OK":
            self.get_logger().info(f"📤 [TX][{status_tag}] -> {data.strip()}")
        else:
            # ถ้าไม่ปกติ ให้เป็นสีเหลือง
            self.get_logger().warn(f"📤 [TX][{status_tag}] -> {data.strip()}")
        
        if self.is_connected and self.serial_conn is not None and self.serial_conn.is_open:
            try:
                self.serial_conn.write(data.encode('utf-8'))
                # Mirror to ROS2 topic
                msg = String()
                msg.data = data.strip()
                self.pub_serial_tx.publish(msg)
            except Exception as e:
                self.get_logger().error(f"Serial write error: {e}")
                self.is_connected = False # สั่งปลดเพื่อให้ Thread ช่วยหาวิธีต่อใหม่
                
    def read_serial_data(self):
        while rclpy.ok():
            if self.is_connected and self.serial_conn and self.serial_conn.is_open:
                try:
                    if self.serial_conn.in_waiting > 0:
                        line = self.serial_conn.readline().decode('utf-8', errors='ignore').strip()
                        if line:
                            # Mirror to ROS2 topic
                            msg = String()
                            msg.data = line
                            self.pub_serial_rx.publish(msg)
                            self.process_stm32_data(line)
                    else:
                        time.sleep(0.01)
                except Exception as e:
                    self.get_logger().debug(f"Error reading STM32 serial: {e}")
                    self.is_connected = False
            else:
                time.sleep(0.1)
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

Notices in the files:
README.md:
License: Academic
